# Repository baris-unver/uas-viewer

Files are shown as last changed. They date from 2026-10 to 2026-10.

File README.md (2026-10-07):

# SkyG Airframe Explorer

Interactive 3D models of SkyG Speed 90 (revision C6-9, `c6/`, also the site root), SkyG Speed 90B (carbon-tube fuselage, `c6b/`), SkyG Speed 120 (`c7/`) and SkyG Speed 180 (`c8/`); SkyG Speed 60 (`c5/`) is archived: exploded view, per-part print data, camera noses,
section cuts, CG and neutral-point marks. Single static page (three.js/WebGL); open `index.html` or the GitHub Pages site.

Generated from the design project by `scripts/viewer_C4.py`; published with `scripts/publish_site.sh`.

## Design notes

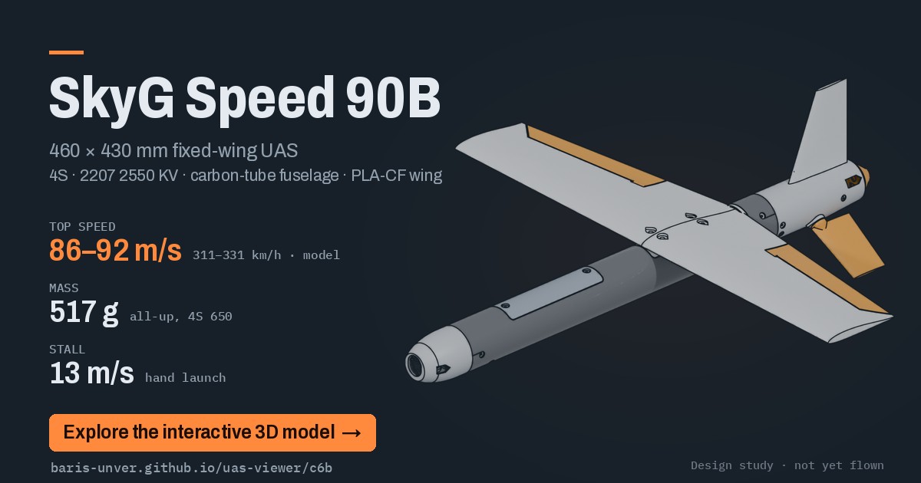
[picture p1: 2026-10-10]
share/C6B-card.jpg

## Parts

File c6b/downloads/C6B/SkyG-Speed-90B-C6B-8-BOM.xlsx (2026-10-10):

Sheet: Order list (BOM)
SkyG Speed 90B order list (BOM)
SkyG Speed 90B · revision C6B-8 · 2026-10-10
Line | Group | Item | Order qty | Qty per aircraft | Must-meet specification | Recommended product / search term | Installed where | Status | Source / note
1 | Avionics | Flight controller | 1 | 1 | 37 x 26 x 14 mm stack max, fixed-wing firmware (INAV/ArduPilot), PDB with current sensor >= 80 A, servo BEC 6 V | SpeedyBee F405 WING MINI | Equipment tray, wing-bay floor (foam tape + strap) | Sourced | https://ardupilot.org/plane/docs/common-speedybeef405wing.html - FC 5.6 g + PDB 5.5 g; 80 A sensor; servo BEC 5 V 4 A, 6 V by jumper (set 6 V); wireless USB extender for setup only; F405: no ArduPilot Lua scripting, so the rpm governor cannot run on it (open item)
2 | Avionics | GNSS + compass | 1 | 1 | M10 GNSS + compass, 25 x 25 x 7.7 mm, 5 V, UART + I2C | TBS M10Q GPS GLONASS (QMC5883 compass), 13.5 g | Bonded carrier under the PLA front hatch cover (its radio window), behind the battery, patch up | Sourced | https://www.robocombo.com/tbs-m10q-gps-glonass-4293 - battery rear stop x=136; compass near the battery leads: compassmot or disable it
3 | Radio | Receiver | 1 | 1 | ELRS 2.4 GHz, <=13x11x3 mm | RadioMaster RP1 V2 | On the equipment tray ahead of the flight controller (x 228-241) | Sourced | https://www.radiomasterrc.com/products/rp1-expresslrs-2-4ghz-nano-receiver; antenna: dipole in the fin on a u.FL coax (inside the carbon tube there is no radio)
4 | Radio | Transmitter | 1 | 0 | ELRS 2.4 GHz, model mixing for V-tail | e.g. RadioMaster Pocket ELRS or Boxer ELRS | Ground | Owner choice | Skip if you already have an ELRS radio
5 | Propulsion | Motor | 2 | 1 | 2207 class, about 2550 KV (4S racing), 5 mm prop shaft, 16 x 16 mm M3, bell <= 28 mm, body <= 21.5 mm, <= 34 g | 2207 2550KV 4S racing motor | Motor shroud (plate M1, 16 x 16 mm pattern) | Sourced | C6: about 600 W bursts; motor bulkhead at x=420.2 for the longer body
6 | Propulsion | Propeller (fixed) | 6 | 1 | APC 5 x 7.5E thin electric (LP05075E), 5 mm bore with adapter ring, pusher orientation, rated 30,000 rpm | APC 5x7.5E (LP05075E) | Motor bell, behind the spinner backplate; thin M5 nut | Class | C5-3: fixed prop with a 77 % flight-controller throttle cap. It hangs below the ground line at rest: expect broken props on belly landings, carry spares
7 | Propulsion | Prop adapter ring | 2 | 1 | APC adapter ring to the 5 mm motor shaft (LPARM12SF set, included with the prop) | APC LPARM12SF adapter rings | Prop hub bore | Class | C5-3; a folding yoke only for the optional folding prop
8 | Propulsion | ESC | 1 | 1 | 4-in-1 70 A AM32 (one channel used): 70 A / 100 A 3 s per channel, 3-8S, bidirectional DShot rpm telemetry, 33 x 43 mm, 13.4 g | HDZero Halo 4in1 70A ESC AM32 | Wing bay, flat on the flight controller (x 248-291), motor on M1 | Sourced | https://fpvdronemarket.com/hdzero-halo-4in1-70a-esc-am32 (2026-10-06: the single 65 A ESC was not available in Turkey). Replace the XT60 lead with XT30; only M1 signal, GND and telemetry from the SH1.0 lead; rpm telemetry feeds the governor. Order 1: if the M1 channel fails, move the motor to M2 (no spare ESC needed)
9 | Controls | Metal-gear micro servo | 4 | 3 | Emax ES9052MD (drawing): case 19.9 x 8.8 mm, 26.35 mm to the spline top, ears 29 mm with 2 mm holes at 25.1 mm, 15T 3.9 mm spline 4.2 mm from one end, metal gears, digital, 1.3 kg cm at 6 V, 5.5 g | Emax ES9052MD or ES9052MD HV (Promodelhobby, Turkey) | 1 wing bay (through the floor onto the bottom skin, output aft at x 323) + 2 tail module (through the F3 floor, output aft at x 374) | Sourced | KST X06 no longer available. No output bearing: check freeplay on the bench; 6 V servo rail
10 | Power | Flight battery | 3 | 1 | 4S LiPo 650 mAh, <= 60 x 31 x 21 mm, XT30, >= 100C (about 50 A bursts) | Tattu R-Line 4S 650 75C (60 x 31 x 21 mm, 74 g) | Front bay floor | Sourced | C6: high-C pack; full power lasts about 40-50 s
11 | Power | Balance charger | 1 | 0 | 4S LiPo balance charging, XT30 lead | e.g. ToolkitRC / ISDT small DC charger + XT30 lead | Ground | Owner choice
12 | Power | XT30 connector pairs | 4 | 1 | XT30 male/female | Amass XT30 | Battery-ESC/PDB | Class
13 | Video | FPV camera | 1 | 1 | 19 x 19 mm micro FPV camera with M2 side holes, <= 9 g (or 14 mm nano in a nano-to-micro bracket) | Micro 19 mm FPV camera, e.g. RunCam Phoenix 2 or Caddx Ratel 2 | N0M nose, on 2 x M2 pivot screws | Class | Digital micro cameras (Walksnail Avatar micro, HDZero micro) also fit; set the lens flush with the nose face
14 | Video | Video transmitter + antenna | 1 | 1 | Board <= 20 x 20 mm, height <= 6 mm, 25-200 mW, legal band/licence for your country and event | 20x20 analog or digital VTX with U.FL antenna | N0M nose shelf, flat | Class | Check competition video rules first; foam tape + zip tie on the shelf; antenna: vertical 5.8 GHz dipole (<= 26 x 3 mm) in the N0M nose clips; with N0MD a thin bare dipole <= 24 x 1.6 mm
15 | Structure | Carbon tube | 2 | 1 | 5.0 mm OD x 3.0 mm ID, >= 400 mm, straight | Pultruded carbon tube 5x3 mm x 500 mm (cut to 400) | Through both wing halves | Class | One tube through both halves (flat wing, no joiner since C4-7e)
17 | Controls | Music wire 2.0 mm | 1 | 2 | 2.0 mm spring steel, >= 250 mm | Music wire 2.0 mm | Aileron torque rods | Class | Two rods of ~95 mm: 12 mm horn bent down at the root with a 4 mm outboard pin at its tip; straight run on the hinge axis to y 80; the last 9 mm filed flat (0.3 mm deep, on the side opposite the horn) and epoxied into the D-bore in the aileron's root knuckle. Pushed in from the wing's root face; C6: one 90° bend per rod (horn leg 6 mm from the centreline), printed horn AHR/AHL glued on the leg
18 | Controls | Pushrods 1.2 mm with Z-bend | 4 | 4 | 1.2 mm steel pushrod with a factory Z-bend, >= 200 mm (cut to length: 2 aileron links about 20 mm, 2 tail pushrods about 75 mm) | Z Tip D1.2mm x 260mm Çelik Pushrod (LXMRC) | Z-bend in the servo arm (hole drilled 1.1 mm, reamed to 1.2 mm), 90° L-bend through the printed horn (reamed the same), keeper on the end | Sourced | https://www.promodelhobby.com/urun/z-tip-d1-2mm-x-260mm-celik-pushrod-itme-cubugu (C6 simple linkage, 2026-10-06)
19 | Controls | Pushrod keepers for 1.2 mm wire | 1 | 4 | Snap-on L-type pushrod keeper for 1.2 mm wire (pack of 5) | Pushrod Tutucu d1,2×L11mm (5 adet) | On the protruding L-bend end at each printed horn (2 ailerons, 2 stabilators) | Sourced | Promodelhobby, Bağlantı Elemanları (in stock 2026-10-06); unclip the tail pair to remove the tail module
20 | Controls | Z-bend pliers, 1.1 mm drill, 1.2 mm drill (as a hand reamer), small flat file | 1 | 0 | Pliers for the 90° L-bends; servo-arm and horn holes drilled 1.1 mm then reamed by hand with the 1.2 mm bit (zero play); flat file for the 0.3 mm flats | Du-Bro Z-bend pliers (or flat-nose pliers) | Tools: servo-arm and horn holes reamed to 1.2 mm, flats on the stabilator shafts (under the printed horns) and the torque rods | Class | No EZ connectors: Z-bends in the KST arms' 0.85 mm holes have less play
21 | Hardware | Steel countersunk screw M3 x 16 | 4 | 2 | Steel countersunk, hex socket (ISO 10642 / DIN 7991), A2 stainless or 8.8 | M3x16 steel countersunk screw | Wing mount, front screws (x = wing LE + 16), one in each wing half 6.5 mm from the centreline, in steel cup washers | Class | C6B (owner 2026-10-08): steel instead of nylon. Snug only: the nut bars are printed PETG-CF
22 | Hardware | M3 hex nut | 8 | 4 | 5.5 mm AF | M3 nuts | Wing screw nuts, two in each bonded nut bar | Class
23 | Hardware | M2 x 6 countersunk screws (joints) | 8 | 4 | M2 x 6 countersunk (DIN 965), steel | M2x6 countersunk screws | Tail-module joint (4: two each side, at the side and 25 deg below), each flush in a printed countersunk washer (CW) in a 5 mm hole in the F3 skin, into the tail coupler's bosses | Class
28 | Consumables | Kapton / thin clear tape | 1 |  | Kapton (polyimide) tape 6-10 mm wide, or thin clear tape | Kapton tape | Gap seals at the aileron hinge lines (applied with slack) | Class | The ailerons are pin-hinged, not tape-hinged
29 | Consumables | Adhesives | 1 |  | Medium CA + activator, 5-min or 30-min epoxy | CA + epoxy | Spars/joiner/tail | Class
30 | Consumables | Velcro strap + hook/loop | 2 | 1 | 10-12 mm battery strap | Battery strap 10x150 mm | Battery | Class
31 | Consumables | Heat shrink + silicone wire | 1 |  | 14 AWG red + black (battery lead and ESC feed, about 0.25 m each colour), 16 AWG black (motor phases, about 0.5 m), 28 AWG in four colours (signals); heat shrink 1.5 / 3 / 4.8 mm |  | Wiring | Class | Cut lengths per cable: Electrical Integration manual (C6, 2026-10-06)
32 | Structure | Silver steel rod 2.5 mm | 1 | 2 | 2.5 mm hardened silver steel, >= 100 mm (tail-panel pivot shafts) | 2.5 mm silver steel rod | Stabilator pivot shafts (2 x 50 mm) | Class | C6: about 6 x the bending stiffness of 1/16 in wire (flutter margin)
33 | Structure | Brass tube 3 mm | 1 | 2 | 3 mm OD x 0.225 mm wall (ID 2.55 mm), telescopes over the 2.5 mm shaft | K&S 3 mm x 0.225 brass tube | Stabilator bushings (2 x 10 mm) in the tail-module bosses | Class | Check the 1/16 in shaft turns freely without play
34 | Power | MR30 connector pairs | 3 | 1 | 3-pin MR30 (motor phases), male/female | Amass MR30 | Tail-module joint, ESC to motor | Class | Lets the tail module unplug
35 | Controls | Servo extension leads 100 mm | 4 | 2 | JR/Futaba 3-pin, 100 mm | Servo extension 100 mm | Tail servo leads: plug pairs lying flat on the floor beside the aileron servo (x 298-326, ahead of the tail joint) | Class | Unplug both, and the MR30, before pulling the tail module
36 | Video | JST-SH/GH lead with plug, 4-6 pin | 2 | 1 | Matches the VTX connector; 100 mm | VTX pigtail extension | Nose joint (VTX power + control) | Class | Choose after the VTX is selected
37 | Video | Camera pivot screws | 4 | 2 | M2 x 10 pan head + M2 washer 5 mm OD | M2x10 pan head screws + M2 washers | N0M nose side seats | Class | Carry spares; 2.5 mm thread engagement in the camera
38 | Test option (Pi) | Raspberry Pi camera | 1 | 0 | 25 x 23.862 mm CSI board, 4 x d2.2 holes on 21 x 12.5 mm | Raspberry Pi Camera Module 3 Wide (or v2 / Module 3) | N0P nose, on 4 posts | Sourced | https://www.raspberrypi.com/documentation/accessories/camera.html - only for the Pi test configuration
39 | Test option (Pi) | CSI camera ribbon | 1 | 0 | 15-pin 1 mm FPC (Pi 4 and earlier) or 22-pin 0.5 mm (Pi 5, Zero), >= 200 mm | Raspberry Pi camera cable | N0P nose to the Pi | Class | Choose to match the Raspberry Pi used
40 | Test option (Pi) | Pi board screws | 4 | 0 | M2 x 5 self-tapping (plastic) | M2x5 self-tapping screws | N0P posts | Class
41 | Test option (Pi) | Nose ballast | 1 | 0 | Up to about 6 g | Tungsten putty (or steel shot in epoxy) | Ceiling ballast cup in the Pi camera noses (N0P / N0PD, x 39-49), tape over | Class | Only if the balance needs it (SkyG Speed 90 with a Pi nose: about 4 g)
42 | Hardware | Motor screws M3 | 8 | 4 | M3 x 6 (check motor thread depth) | M3x6 socket screws | Motor to plate M1, fitted on the bench before the plate goes in | Class | Heads on the plate's front face sit in the bulkhead recesses
44 | Test equipment | Thrust stand / wattmeter | 1 | 0 | Measures thrust, current, rpm and power up to 70 A | Small motor thrust stand + inline wattmeter | Bench | Owner choice | Needed for the C5 test plan (thrust >= 500 g, current <= 30 A)
48 | Propulsion | Thin M5 nut | 4 | 1 | M5 DIN 439 thin nut (2.7 mm), steel; medium thread locker | M5 thin jam nut DIN 439 | Prop on the motor shaft | Class | The standard prop nut is too tall for the 460 mm limit
53 | Hardware | Steel countersunk screw M3 x 12 | 4 | 2 | Steel countersunk, hex socket (ISO 10642 / DIN 7991), A2 stainless or 8.8 | M3x12 steel countersunk screw | Wing mount, rear screws (x = wing LE + 58, ahead of the aileron horns), one in each wing half 6.5 mm from the centreline, in steel cup washers | Class | C6B (owner 2026-10-08): steel instead of nylon. Snug only: the nut bars are printed PETG-CF
83 | Hardware | Steel cup washer M3 (countersunk finishing washer) | 10 | 4 | Countersunk finishing (cup) washer for M3, about 8 mm OD x 1.8 mm, steel black oxide (or A2 stainless) | M3 countersunk finishing washer black | Under the four M3 wing screws, flush in the recesses in the wing top | Class | Owner 2026-10-08: steel cup washers on the wing and hatch screws (removed most often); the recess is 8.3 mm x 1.85 mm: check your washers
84 | Hardware | Steel cup washer M2 (countersunk finishing washer) | 10 | 2 | Countersunk finishing (cup) washer for M2, about 6 mm OD x 1.4 mm, A2 stainless (non-magnetic: the rear one is 5 mm from the GPS compass) | M2 countersunk finishing washer black | Under the two M2 hatch screws, flush in the recesses in the hatch cover | Class | Owner 2026-10-08; the recess is 6.3 mm x 1.45 mm: check your washers
54 | Hardware | M2 x 6 countersunk screws (motor plate) | 4 | 2 | M2 x 6 countersunk (DIN 965), steel | M2x6 countersunk screws | Motor plate M1: one each side, flush in a printed countersunk washer (CW) in a 5 mm counterbore in the tail module's side, into the plate's lugs (in pockets in the seat ring) | Class | C6B-6 (owner 2026-10-08): screwed in instead of bonded; the plate comes out for a different motor
55 | Consumables | Servo strap / zip tie + foam tape | 2 | 1 | 3 mm zip tie or 6 mm strap; double-sided foam tape | Small zip ties + servo tape | All three servos: foam tape on the bottom skin through the floor cut-outs, strap over the case | Class | Removable: the servos come out for motor service
56 | Structure | Steel rod 1.5 mm | 1 | 2 | 1.5 mm music wire or silver steel, >= 270 mm (2 x 132 mm) | Music wire 1.5 mm | Aileron hinge pin + spine on the hinge axis (y 82-214) | Class | Pushed in from the wingtip through the tip bore, the aileron and the two wing knuckles; bonded in the aileron with thin CA through its 3 glue holes, free in the knuckles and the tip. Plug the tip hole
57 | Video option (DJI) | DJI O4 Air Unit (Lite) | 1 | 1 | DJI O4 Air Unit (8.2 g with camera): camera 13.44 x 12.36 x 16.5 mm in a 14 x 20 mm mount, module 30 x 30 x 6 mm (4 x d2.6 on 25.5 mm), 3.7-13.2 V | DJI O4 Air Unit | N0O nose: camera in its mount clamped by 4 x M2 x 5 through the side bosses (fitted from the back); module in the separate duct insert DT (C6B-8) | Option | https://www.dji.com/o4-air-unit/specs (dimensions: O4 Air Unit Series User Manual v1.0, sec. 1.2) - replaces the micro camera + VTX; power from the SpeedyBee Vv pad set to the servo BEC (6 V jumper); needs airflow (shuts down after minutes on the bench) C6B-8: fit order antenna (clips, left wall), camera, then the module in the duct insert, then the insert through the spigot; cooling air from the NACA inlet on the right side, out through the tube
58 | Video option (DJI) | M2 x 5 pan head (O4 camera mount) | 4 | 4 | M2 x 5 pan head (or the screws supplied with the camera) | M2x5 pan head screws | N0O / N0OD side bosses into the camera mount | Class | At most 3.1 mm into the mount's d1.65 holes; fore-aft slots +-1 mm
59 | Video option (DJI) | Foam strip + tape (O4 module) | 1 | 1 | 2 x 1 mm foam strip, 25 mm; Kapton or aluminium tape | Double-sided foam tape, Kapton tape | Module retention in the nose duct | Class | Foam strip in the top groove, tape over the rear edge; nothing may cover the module's faces (they are the cooling surfaces)
60 | Video option (DJI) | O4 3-in-1 lead extension | 1 | 1 | ~200 mm, power + UART, plug at the nose joint | Silicone wire + JST-SH / matching plug | Nose to the flight controller in the wing bay | Class | MSP DisplayPort OSD on a spare SpeedyBee UART
61 | Consumables | Vent tape | 1 | 1 | Thin smooth tape (e.g. 3M 471 or Kapton), 15 mm | Vinyl or Kapton tape | Over the nose belly inlet, for record passes only (no openings in the tube or the hatch cover on C6B) | Class | Never over the DJI nose's duct openings (the module overheats in about a minute without them)
65 | Controls | 15T servo arms | 1 | 1 | 15T 3.9-4 mm spline arms: two-sided (aileron) with holes at 4.3 mm, one-sided (tail) with a hole at 6.7 mm; C6: holes drilled 1.1 mm and reamed to 1.2 mm for the 1.2 mm Z-bends (no play) | Arms supplied with the ES9052MD (drill a 0.85 mm hole at the radius if missing) or a KST X06 arm set | Aileron servo: two-sided arm; tail servos: one-sided arms | Class | Usually supplied with the servos
66 | Radio | u.FL extension 1.13 mm, about 250 mm | 1 | 1 | IPEX / u.FL male to u.FL female 1.13 mm coax, 200-300 mm | u.FL IPEX extension cable 1.13 mm | RP1 V2 receiver to the dipole in the fin (W07), u.FL joint at the tail joint | Class | C6: ELRS dipole in the fin (2026-10-06)
67 | Power | Dupont housings + crimps (1-pin, 4-pin) | 1 | 3 | 2.54 mm Dupont female housings with crimp terminals | Dupont connector kit 2.54 mm | ESC signal and GND on S1 (2 x 1-pin), receiver lead on the FC receiver header (4-pin) | Class
68 | Structure | Carbon-fibre tube 40 x 38 mm | 1 (2 m makes 6) | 320 mm | Roll-wrapped 3K carbon/epoxy, 40.0 mm OD x 38.0 mm ID (1 mm wall), about 178 g/m; straight, round within 0.1 mm | Karbon boru 40/38 mm 3K (Kompozit Pazari RFG 2 m; Karbonfiber Boru; PilotTR) | Fuselage x 50-350: camera nose plugs in the front, tail module onto the coupler at the back | Ordered (owner, 2026-10-07) | Measure the bore before printing (parameters: fuselage.tube.id); cut length 300 mm, windows and holes from the paper template; 42.8 g as cut
69 | Hardware | M2 x 6 countersunk screws (tube) | 12 | 8 | M2 x 6 countersunk (DIN 965 / ISO 7046), steel | M2x6 countersunk screws | Flush in a printed countersunk washer (CW; print 14: 8 in the tube, 4 at the tail joint, 2 at the motor plate) in each 5 mm hole in the tube: camera-nose joint (2, 10 mm from the tube's end), equipment tray (4), tail coupler (2, 40 deg above the side line, 12 mm from the tube's end; backup to the bond) | Class | Owner 2026-10-08: no screw heads standing out; the washer carries the head (no countersink in the 1 mm carbon)
70 | Consumables | Structural epoxy | 1 | ~3 g | 2-part structural epoxy (30-min working time or longer), bonds carbon and PLA; scuff the carbon with 120-grit and clean with alcohol first | e.g. UHU Plus Endfest 300, Loctite EA 3430 or laminating epoxy thickened with cotton flock | Nut bars, hatch lips, duct inserts, tail coupler and the wing saddle into / onto the tube | Class
71 | Consumables | Thin CA | 1 | ~1 g | Thin cyanoacrylate | Thin CA glue | Seal every cut edge and hole in the carbon tube | Class | Carbon conducts: a frayed edge can cut through a wire's insulation and short it
72 | Tools | Diamond cut-off discs + dust protection | 1 | - | Rotary-tool diamond cut-off discs (or reinforced abrasive), fine file, FFP3 mask, eye protection, vacuum at the disc or cut wet | Dremel 545 diamond disc or equivalent | Cutting the tube to length and its windows | Owner has a Dremel | Carbon dust is a lung irritant and conductive (keep it off electronics)
77 | Hardware | M2 x 6 countersunk screws (hatch) | 4 | 2 | M2 x 6 countersunk (DIN 965), steel | M2x6 countersunk screws | Front hatch cover, one at each end, into the bosses under the bonded lips | Class | C6B-4 (owner): no magnets
78 | Avionics | USB-C extension with socket | 1 | 1 | USB-C female socket board or panel-mount socket (about 10 x 8 mm) on a 150 mm USB-C extension, thin cable | USB-C female panel mount extension 15 cm | FC USB-C to the socket holder on the tray under the hatch cover (left of the GPS lead) | Class | C6B-4: FC access for setup, parameters and logs with the hatch cover off
89 | Consumables | Conformal coating | 1 | ~2 ml | Acrylic or silicone conformal coating for PCBs (e.g. MG Chemicals 419D / 422B), brush or spray | PCB conformal coating | Flight controller, ESC, receiver and VTX / O4 module boards (not on connectors, the USB socket, the barometer port or the module's heat faces) | Class | C6B-8 (owner: rain can reach the electronics): the cooling air reaches them through the tube; mask connectors before coating
90 | Consumables | Filament PLA-CF | 1 | 94 g | Bambu PLA-CF 1 kg (hardened-steel nozzle) | Bambu PLA-CF 1 kg (hardened-steel nozzle) | Wing halves WR/WL (2 walls, 8 % gyroid) | Bambu profile | C6B per-part filaments (design/MATERIALS-NOTES.md); one aircraft with the N0M nose
91 | Consumables | Filament PETG-CF | 1 | 55 g | Bambu PETG-CF 1 kg (hardened-steel nozzle) | Bambu PETG-CF 1 kg (hardened-steel nozzle) | Ailerons, equipment tray, tail coupler, nut bars, hatch lips, duct inserts, motor plate, spinner | Bambu profile | C6B per-part filaments (design/MATERIALS-NOTES.md); one aircraft with the N0M nose
92 | Consumables | Filament ASA | 1 | 21 g | Bambu ASA 1 kg (enclosed printer) | Bambu ASA 1 kg (enclosed printer) | Tail module F3 | Bambu profile | C6B per-part filaments (design/MATERIALS-NOTES.md); one aircraft with the N0M nose
93 | Consumables | Filament PETG | 1 | 20 g | Bambu PETG Basic 1 kg | Bambu PETG Basic 1 kg | Camera noses, VTX shelf, hatch cover, GPS carrier | Bambu profile | C6B per-part filaments (design/MATERIALS-NOTES.md); one aircraft with the N0M nose

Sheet: Printed parts
SkyG Speed 90B printed parts (Bambu Studio, Bambu Lab H2S 0.4 nozzle)
SkyG Speed 90B · revision C6B-8 · 2026-10-10
Part | Material | Mass (g) | Print time (h) | Walls | Infill
N0M-nose-micro-camera | PETG | 13.9 | 1.24 | 2 | 30 %
N0P-nose-pi-camera | PETG | 13.2 | 1.07 | 2 | 30 %
N0M-vtx-shelf | PETG | 0.8 | 0.13 | 2 | 30 %
N0O-nose-dji-o4 | PETG | 14.7 | 1.25 | 2 | 30 %
N0O-duct-insert | PLA Aero | 3.6 | 0.62 | 2 | 30 %
F3-tail-module | ASA | 14.3 | 2.02 | 2 | 30 %
HF-front-hatch | PETG | 4.3 | 1.42 | 2 | 30 %
HG-gps-carrier | PETG | 1.1 | 0.33 | 2 | 30 %
TR-equipment-tray | PETG-CF | 17.8 | 0.83 | 2 | 30 %
TC-tail-coupler | PETG-CF | 8.5 | 0.48 | 2 | 30 %
CW-countersunk-washer | PETG-CF | 0.1 | 0.1 | 2 | 30 %
WF-wing-window-filler | PETG-CF | 1.4 | 0.49 | 2 | 30 %
NB1-wing-nut-bar-front | PETG-CF | 1.2 | 0.2 | 2 | 30 %
NB2-wing-nut-bar-rear | PETG-CF | 1.3 | 0.2 | 2 | 30 %
HL1-hatch-lip-front | PETG-CF | 0.9 | 0.23 | 2 | 30 %
HL2-hatch-lip-rear | PETG-CF | 0.9 | 0.23 | 2 | 30 %
WR-wing-right | PLA-CF | 47.2 | 2.98 | 2 | 8 %
WL-wing-left | PLA-CF | 47.3 | 3 | 2 | 8 %
AR-aileron-right | PETG-CF | 4 | 1.22 | 1 | 5 %
AL-aileron-left | PETG-CF | 3.8 | 1.19 | 1 | 5 %
SR-stabilator-right | PETG-CF | 5.2 | 0.62 | 2 | 10 %
SL-stabilator-left | PETG-CF | 5.2 | 0.63 | 2 | 10 %
M1-motor-plate | PETG-CF | 2.1 | 0.23 | 4 | 40 %
FN-fin | ASA | 6.7 | 1.53 | 2 | 30 %
SP-spinner | PETG-CF | 1.6 | 0.23 | 4 | 40 %
AHR-aileron-horn-right | PETG-CF | 0.2 | 0.15 | 4 | 40 %
AHL-aileron-horn-left | PETG-CF | 0.2 | 0.15 | 4 | 40 %
THR-tail-horn-right | PETG-CF | 0.3 | 0.13 | 4 | 40 %
THL-tail-horn-left | PETG-CF | 0.3 | 0.13 | 4 | 40 %
One aircraft (one aircraft with the N0M nose; N0P is an alternative part): 190.6 g, 20.1 h of printing.
Print every part with supports OFF, in the orientation of the user manual (all parts pass the print audit, design/DFAM-RULES.md).
Only one camera nose is needed; the other noses (and their dome ring or VTX shelf) are options.

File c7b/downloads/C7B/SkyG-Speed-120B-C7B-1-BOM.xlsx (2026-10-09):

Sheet: Order list (BOM)
SkyG Speed 120B order list (BOM)
SkyG Speed 120B · revision C7B-1 · 2026-10-09
Line | Group | Item | Order qty | Qty per aircraft | Must-meet specification | Recommended product / search term | Installed where | Status | Source / note
1 | Avionics | Flight controller | 1 | 1 | 37 x 26 x 14 mm stack max, fixed-wing firmware (INAV/ArduPilot), PDB with current sensor >= 80 A, servo BEC 6 V | SpeedyBee F405 WING MINI | Equipment tray, front bay: on two printed ledges above the ESC, under the front hatch (foam tape + strap) | Sourced | https://ardupilot.org/plane/docs/common-speedybeef405wing.html - FC 5.6 g + PDB 5.5 g; 80 A sensor; servo BEC 5 V 4 A, 6 V by jumper (set 6 V); F405: no ArduPilot Lua scripting, so no rpm governor: the throttle is capped (THR_MAX about 70 %) so the prop stays at 38,000 rpm on a full 6S pack (owner 2026-10-09: same FC as SkyG Speed 90B)
2 | Avionics | GNSS + compass | 1 | 1 | M10 GNSS + compass, 25 x 25 x 7.7 mm, 5 V, UART + I2C | TBS M10Q GPS GLONASS (QMC5883 compass), 13.5 g | Cradle under the PETG front hatch cover (its radio window), above the front battery pair, patch up | Sourced | https://www.robocombo.com/tbs-m10q-gps-glonass-4293 - the compass is 10-30 mm from the battery leads and the charge port: compassmot or disable it
3 | Radio | Receiver | 1 | 1 | ELRS 2.4 GHz, <=13x11x3 mm | RadioMaster RP1 V2 | On edge on the right FC ledge (x 100-113), foam tape | Sourced | https://www.radiomasterrc.com/products/rp1-expresslrs-2-4ghz-nano-receiver; antenna: dipole in the fin on a u.FL coax (inside the carbon tube there is no radio)
4 | Radio | Transmitter | 1 | 0 | ELRS 2.4 GHz, model mixing for V-tail | e.g. RadioMaster Pocket ELRS or Boxer ELRS | Ground | Owner choice | Skip if you already have an ELRS radio
5 | Propulsion | Motor | 2 | 1 | 2207 class rated for 6S, 2100-2200 KV, 5 mm shaft or M5 prop thread, 16 x 16 mm M3, bell <= 28 mm, body <= 21.5 mm, >= 50 A peak | T-Motor F50 2207 2150KV | Motor shroud (plate M1, 16 x 16 mm pattern) | Owner has | Same motor as SkyG Speed 60 (C5). T-Motor rates it for 24 V (6S): 50 mOhm, 54.8 A / 1273 W peak. Robocombo lists it (https://www.robocombo.com/t-motor-latest-f50-5inch-racing-motor-2150kv--4160, 0 in stock on 2026-10-02); alternative VCI 2207 Pro 2110KV (Pyrodrone, in stock). The Velox V3 1950KV (Robocombo stock) gives about 110 m/s. SkyG Speed 120B: owner has it (2026-10-09)
6 | Propulsion | Propeller (fixed) | 8 | 1 | Gemfan Vortex 5 x 7.5 (glass-fibre polyamide), 6.35 mm bore with the 5 mm adapter ring; spin-tested to 45,600 rpm before use; operating ceiling 38,000 rpm (throttle cap) | Gemfan 5x7.5E Vortex | Motor bell, behind the spinner backplate; thin M5 nut | Owner has | Owner has it (2026-10-09). No published rpm rating: spin-test each batch to 1.2 x the 38,000 rpm ceiling behind a shield, then inspect. No governor on the F405: THR_MAX about 70 % holds an unloaded prop on a full pack at 38,000 rpm. Pusher: mount the E front face toward the motor with the motor reversed in the ESC (5x7.5R: Pyrodrone import). Balance prop + spinner carefully
7 | Propulsion | Prop adapter ring | 2 | 1 | 5 mm ring from the Gemfan adapter set (3/4/5/6/7 mm, included) | Gemfan adapter rings (with the prop) | Prop hub bore | Class | C5-3; a folding yoke only for the optional folding prop
8 | Propulsion | ESC | 1 | 1 | 4-in-1 70 A AM32 (one channel used): 70 A / 100 A 3 s per channel, 3-8S (6S used), bidirectional DShot rpm telemetry, 33 x 43 mm, 13.4 g | HDZero Halo 4in1 70A ESC AM32 | Front bay: flat on two rails on the tray's front floor (x 86-129), under the FC; slid in from behind before the packs, motor on M1 | Sourced | https://fpvdronemarket.com/hdzero-halo-4in1-70a-esc-am32 (owner 2026-10-09: the same ESC as SkyG Speed 90B, the Sequre 70 A is not available). Replace the XT60 lead with XT30; only M1 signal, GND and telemetry from the SH1.0 lead. About 65 A at full throttle on the ground (model), 60 A at top speed: inside the 70 A channel rating. Order 1: if M1 fails, move the motor to M2
9 | Controls | Metal-gear micro servo | 4 | 3 | Emax ES9052MD (drawing): case 19.9 x 8.8 mm, 26.35 mm to the spline top, ears 29 mm with 2 mm holes at 25.1 mm, 15T 3.9 mm spline 4.2 mm from one end, metal gears, digital, 1.3 kg cm at 6 V, 5.5 g | Emax ES9052MD or ES9052MD HV (Promodelhobby, Turkey) | 1 wing bay (through the floor onto the bottom skin, output aft at x 323) + 2 tail module (through the F3 floor, output aft at x 374) | Sourced | KST X06 no longer available. No output bearing: check freeplay on the bench; 6 V servo rail
10 | Power | Flight battery | 8 | 4 | 3S LiPo 680 mAh, <= 81 x 15.5 x 20 mm, XT30, >= 95C; four per aircraft: each side-by-side pair in series (6S 680), the two pairs in parallel (6S 1360 mAh, 194 g) | BetaFPV LAVA II 3S 680 95C LiHV (2-pack) | On the tray under the wing (x 138-308 at the nominal balance position), strapped; stays in the aircraft | Sourced | https://fpvdronemarket.com/lava-ii-3s-battery-680mah-2pcs (2,323 TL per 2 on 2026-10-02); 48.5 g each. The packs stay in the aircraft and are charged through the port under the hatch (owner 2026-10-09). Charge to 4.20 V/cell (LiPo mode), not LiHV: 6S full = 25.2 V, the ESC's limit. Use four packs of the same batch and cycles; never connect the pairs at different voltages. Order 8: one set flies, one spare set
11 | Power | Balance charger | 1 | 0 | 6S LiPo balance charging at <= 1C (1.4 A), LiPo mode 4.20 V/cell, XT30 lead and a 6S (7-pin JST-XH) balance lead; storage-charge function | e.g. ToolkitRC / ISDT small DC charger + XT30 lead | Ground | Owner choice | Charge in the aircraft, attended, on a non-flammable surface; inspect the packs (tray out) after any hard landing
12 | Power | XT30 connector pairs | 6 | 2 | XT30 male/female | Amass XT30 | ESC lead to the charge / arming port; spare for the charger lead | Class
13 | Video | FPV camera | 1 | 1 | 19 x 19 mm micro FPV camera with M2 side holes, <= 9 g (or 14 mm nano in a nano-to-micro bracket) | Micro 19 mm FPV camera, e.g. RunCam Phoenix 2 or Caddx Ratel 2 | N0M nose, on 2 x M2 pivot screws | Class | Digital micro cameras (Walksnail Avatar micro, HDZero micro) also fit; set the lens flush with the nose face
14 | Video | Video transmitter + antenna | 1 | 1 | Board <= 20 x 20 mm, height <= 6 mm, 25-200 mW, legal band/licence for your country and event | 20x20 analog or digital VTX with U.FL antenna | N0M nose shelf, flat | Class | Check competition video rules first; foam tape + zip tie on the shelf; antenna: vertical 5.8 GHz dipole (<= 26 x 3 mm) in the N0M nose clips; with N0MD a thin bare dipole <= 24 x 1.6 mm
15 | Structure | Carbon tube | 2 | 1 | 5.0 mm OD x 3.0 mm ID, >= 400 mm, straight | Pultruded carbon tube 5x3 mm x 500 mm (cut to 400) | Through both wing halves | Class | One tube through both halves (flat wing, no joiner since C4-7e)
17 | Controls | Music wire 2.0 mm | 1 | 2 | 2.0 mm spring steel, >= 250 mm | Music wire 2.0 mm | Aileron torque rods | Class | Two rods of ~95 mm: 12 mm horn bent down at the root with a 4 mm outboard pin at its tip; straight run on the hinge axis to y 80; the last 9 mm filed flat (0.3 mm deep, on the side opposite the horn) and epoxied into the D-bore in the aileron's root knuckle. Pushed in from the wing's root face; C6: one 90° bend per rod (horn leg 6 mm from the centreline), printed horn AHR/AHL glued on the leg
18 | Controls | Pushrods 1.2 mm with Z-bend | 4 | 4 | 1.2 mm steel pushrod with a factory Z-bend, >= 200 mm (cut to length: 2 aileron links about 20 mm, 2 tail pushrods about 75 mm) | Z Tip D1.2mm x 260mm Çelik Pushrod (LXMRC) | Z-bend in the servo arm (hole drilled 1.1 mm, reamed to 1.2 mm), 90° L-bend through the printed horn (reamed the same), keeper on the end | Sourced | https://www.promodelhobby.com/urun/z-tip-d1-2mm-x-260mm-celik-pushrod-itme-cubugu (C6 simple linkage, 2026-10-06)
19 | Controls | Pushrod keepers for 1.2 mm wire | 1 | 4 | Snap-on L-type pushrod keeper for 1.2 mm wire (pack of 5) | Pushrod Tutucu d1,2×L11mm (5 adet) | On the protruding L-bend end at each printed horn (2 ailerons, 2 stabilators) | Sourced | Promodelhobby, Bağlantı Elemanları (in stock 2026-10-06); unclip the tail pair to remove the tail module
20 | Controls | Z-bend pliers, 1.1 mm drill, 1.2 mm drill (as a hand reamer), small flat file | 1 | 0 | Pliers for the 90° L-bends; servo-arm and horn holes drilled 1.1 mm then reamed by hand with the 1.2 mm bit (zero play); flat file for the 0.3 mm flats | Du-Bro Z-bend pliers (or flat-nose pliers) | Tools: servo-arm and horn holes reamed to 1.2 mm, flats on the stabilator shafts (under the printed horns) and the torque rods | Class | No EZ connectors: Z-bends in the KST arms' 0.85 mm holes have less play
21 | Hardware | Steel countersunk screw M3 x 16 | 4 | 2 | Steel countersunk, hex socket (ISO 10642 / DIN 7991), A2 stainless or 8.8 | M3x16 steel countersunk screw | Wing mount, front screws (x = wing LE + 16), one in each wing half 6.5 mm from the centreline, in steel cup washers | Class | C6B (owner 2026-10-08): steel instead of nylon. Snug only: the nut bars are printed PETG-CF
22 | Hardware | M3 hex nut | 8 | 4 | 5.5 mm AF | M3 nuts | Wing screw nuts, two in each bonded nut bar | Class
23 | Hardware | M2 x 6 countersunk screws (joints) | 8 | 4 | M2 x 6 countersunk (DIN 965), steel | M2x6 countersunk screws | Tail-module joint (4: two each side, at the side and 25 deg below), each flush in a printed countersunk washer (CW) in a 5 mm hole in the F3 skin, into the tail coupler's bosses | Class
28 | Consumables | Kapton / thin clear tape | 1 |  | Kapton (polyimide) tape 6-10 mm wide, or thin clear tape | Kapton tape | Gap seals at the aileron hinge lines (applied with slack) | Class | The ailerons are pin-hinged, not tape-hinged
29 | Consumables | Adhesives | 1 |  | Medium CA + activator, 5-min or 30-min epoxy | CA + epoxy | Spars/joiner/tail | Class
30 | Consumables | Velcro strap + hook/loop | 2 | 2 | 10-12 mm battery strap, >= 200 mm | Battery strap 10x150 mm | One round each pack pair and the tray floor (slots at x 180 and 266) | Class
31 | Consumables | Heat shrink + silicone wire | 1 |  | 14 AWG red + black (battery lead and ESC feed, about 0.25 m each colour), 16 AWG black (motor phases, about 0.5 m), 28 AWG in four colours (signals); heat shrink 1.5 / 3 / 4.8 mm |  | Wiring | Class | Cut lengths per cable: Electrical Integration manual (C6, 2026-10-06)
32 | Structure | Silver steel rod 2.5 mm | 1 | 2 | 2.5 mm hardened silver steel, >= 120 mm (tail-panel pivot shafts) | 2.5 mm silver steel rod | Stabilator pivot shafts (2 x 59 mm) | Class | C6: about 6 x the bending stiffness of 1/16 in wire (flutter margin)
33 | Structure | Brass tube 3 mm | 1 | 2 | 3 mm OD x 0.225 mm wall (ID 2.55 mm), telescopes over the 2.5 mm shaft | K&S 3 mm x 0.225 brass tube | Stabilator bushings (2 x 10 mm) in the tail-module bosses | Class | Check the 1/16 in shaft turns freely without play
34 | Power | MR30 connector pairs | 3 | 1 | 3-pin MR30 (motor phases), male/female | Amass MR30 | Tail-module joint, ESC to motor | Class | Lets the tail module unplug
35 | Controls | Servo extension leads 300 mm | 4 | 3 | JR/Futaba 3-pin, 300 mm | Servo extension 300 mm | Tail servo leads (plug pairs beside the aileron servo) and the aileron servo lead, along the tube walls past the packs to the FC in the front bay | Class | C7B: the FC is in the front bay, about 200 mm ahead of the aileron servo
36 | Video | JST-SH/GH lead with plug, 4-6 pin | 2 | 1 | Matches the VTX connector; 100 mm | VTX pigtail extension | Nose joint (VTX power + control) | Class | Choose after the VTX is selected
37 | Video | Camera pivot screws | 4 | 2 | M2 x 10 pan head + M2 washer 5 mm OD | M2x10 pan head screws + M2 washers | N0M nose side seats | Class | Carry spares; 2.5 mm thread engagement in the camera
38 | Test option (Pi) | Raspberry Pi camera | 1 | 0 | 25 x 23.862 mm CSI board, 4 x d2.2 holes on 21 x 12.5 mm | Raspberry Pi Camera Module 3 Wide (or v2 / Module 3) | N0P nose, on 4 posts | Sourced | https://www.raspberrypi.com/documentation/accessories/camera.html - only for the Pi test configuration
39 | Test option (Pi) | CSI camera ribbon | 1 | 0 | 15-pin 1 mm FPC (Pi 4 and earlier) or 22-pin 0.5 mm (Pi 5, Zero), >= 200 mm | Raspberry Pi camera cable | N0P nose to the Pi | Class | Choose to match the Raspberry Pi used
40 | Test option (Pi) | Pi board screws | 4 | 0 | M2 x 5 self-tapping (plastic) | M2x5 self-tapping screws | N0P posts | Class
41 | Test option (Pi) | Nose ballast | 1 | 0 | Up to about 6 g | Tungsten putty (or steel shot in epoxy) | Ceiling ballast cup in the Pi camera noses (N0P / N0PD, x 39-49), tape over | Class | Only if the balance needs it (SkyG Speed 90 with a Pi nose: about 4 g)
42 | Hardware | Motor screws M3 | 8 | 4 | M3 x 6 (check motor thread depth) | M3x6 socket screws | Motor to plate M1, fitted on the bench before the plate goes in | Class | Heads on the plate's front face sit in the bulkhead recesses
44 | Test equipment | Thrust stand / wattmeter | 1 | 0 | Measures thrust, current, rpm and power up to 70 A | Small motor thrust stand + inline wattmeter | Bench | Owner choice | Needed for the C5 test plan (thrust >= 500 g, current <= 30 A)
48 | Propulsion | Thin M5 nut | 4 | 1 | M5 DIN 439 thin nut (2.7 mm), steel; medium thread locker | M5 thin jam nut DIN 439 | Prop on the motor shaft | Class | The standard prop nut is too tall for the 460 mm limit
53 | Hardware | Steel countersunk screw M3 x 12 | 4 | 2 | Steel countersunk, hex socket (ISO 10642 / DIN 7991), A2 stainless or 8.8 | M3x12 steel countersunk screw | Wing mount, rear screws (x = wing LE + 58, ahead of the aileron horns), one in each wing half 6.5 mm from the centreline, in steel cup washers | Class | C6B (owner 2026-10-08): steel instead of nylon. Snug only: the nut bars are printed PETG-CF
83 | Hardware | Steel cup washer M3 (countersunk finishing washer) | 10 | 4 | Countersunk finishing (cup) washer for M3, about 8 mm OD x 1.8 mm, steel black oxide (or A2 stainless) | M3 countersunk finishing washer black | Under the four M3 wing screws, flush in the recesses in the wing top | Class | Owner 2026-10-08: steel cup washers on the wing and hatch screws (removed most often); the recess is 8.3 mm x 1.85 mm: check your washers
84 | Hardware | Steel cup washer M2 (countersunk finishing washer) | 10 | 2 | Countersunk finishing (cup) washer for M2, about 6 mm OD x 1.4 mm, A2 stainless (non-magnetic: the rear one is 5 mm from the GPS compass) | M2 countersunk finishing washer black | Under the two M2 hatch screws, flush in the recesses in the hatch cover | Class | Owner 2026-10-08; the recess is 6.3 mm x 1.45 mm: check your washers
54 | Hardware | M2 x 6 countersunk screws (motor plate) | 4 | 2 | M2 x 6 countersunk (DIN 965), steel | M2x6 countersunk screws | Motor plate M1: one each side, flush in a printed countersunk washer (CW) in a 5 mm counterbore in the tail module's side, into the plate's lugs (in pockets in the seat ring) | Class | C6B-6 (owner 2026-10-08): screwed in instead of bonded; the plate comes out for a different motor
55 | Consumables | Servo strap / zip tie + foam tape | 2 | 1 | 3 mm zip tie or 6 mm strap; double-sided foam tape | Small zip ties + servo tape | All three servos: foam tape on the bottom skin through the floor cut-outs, strap over the case | Class | Removable: the servos come out for motor service
56 | Structure | Steel rod 1.5 mm | 1 | 2 | 1.5 mm music wire or silver steel, >= 270 mm (2 x 132 mm) | Music wire 1.5 mm | Aileron hinge pin + spine on the hinge axis (y 82-214) | Class | Pushed in from the wingtip through the tip bore, the aileron and the two wing knuckles; bonded in the aileron with thin CA through its 3 glue holes, free in the knuckles and the tip. Plug the tip hole
57 | Video option (DJI) | DJI O4 Air Unit (Lite) | 1 | 1 | DJI O4 Air Unit (8.2 g with camera): camera 13.44 x 12.36 x 16.5 mm in a 14 x 20 mm mount, module 30 x 30 x 6 mm (4 x d2.6 on 25.5 mm), 3.7-13.2 V | DJI O4 Air Unit | N0O or N0OD nose (camera + module) | Option | https://www.dji.com/o4-air-unit/specs (dimensions: O4 Air Unit Series User Manual v1.0, sec. 1.2) - replaces the micro camera + VTX; power from the SpeedyBee Vv pad set to the servo BEC (6 V jumper); needs airflow (shuts down after minutes on the bench)
58 | Video option (DJI) | M2 x 5 pan head (O4 camera mount) | 4 | 4 | M2 x 5 pan head (or the screws supplied with the camera) | M2x5 pan head screws | N0O / N0OD side bosses into the camera mount | Class | At most 3.1 mm into the mount's d1.65 holes; fore-aft slots +-1 mm
59 | Video option (DJI) | Foam strip + tape (O4 module) | 1 | 1 | 2 x 1 mm foam strip, 25 mm; Kapton or aluminium tape | Double-sided foam tape, Kapton tape | Module retention in the nose duct | Class | Foam strip in the top groove, tape over the rear edge; nothing may cover the module's faces (they are the cooling surfaces)
60 | Video option (DJI) | O4 3-in-1 lead extension | 1 | 1 | ~200 mm, power + UART, plug at the nose joint | Silicone wire + JST-SH / matching plug | Nose to the flight controller in the wing bay | Class | MSP DisplayPort OSD on a spare SpeedyBee UART
61 | Consumables | Vent tape | 1 | 1 | Thin smooth tape (e.g. 3M 471 or Kapton), 15 mm | Vinyl or Kapton tape | Over the nose belly inlet, for record passes only (no openings in the tube or the hatch cover on C6B) | Class | Never over the DJI nose's duct openings (the module overheats in about a minute without them)
65 | Controls | 15T servo arms | 1 | 1 | 15T 3.9-4 mm spline arms: two-sided (aileron) with holes at 4.3 mm, one-sided (tail) with a hole at 6.7 mm; C6: holes drilled 1.1 mm and reamed to 1.2 mm for the 1.2 mm Z-bends (no play) | Arms supplied with the ES9052MD (drill a 0.85 mm hole at the radius if missing) or a KST X06 arm set | Aileron servo: two-sided arm; tail servos: one-sided arms | Class | Usually supplied with the servos
66 | Radio | u.FL extension 1.13 mm, about 250 mm | 1 | 1 | IPEX / u.FL male to u.FL female 1.13 mm coax, 200-300 mm | u.FL IPEX extension cable 1.13 mm | RP1 V2 receiver to the dipole in the fin (W07), u.FL joint at the tail joint | Class | C6: ELRS dipole in the fin (2026-10-06)
67 | Power | Dupont housings + crimps (1-pin, 4-pin) | 1 | 3 | 2.54 mm Dupont female housings with crimp terminals | Dupont connector kit 2.54 mm | ESC signal and GND on S1 (2 x 1-pin), receiver lead on the FC receiver header (4-pin) | Class
68 | Structure | Carbon-fibre tube 50 x 48 mm | 1 (2 m makes 6) | 320 mm | Roll-wrapped 3K carbon/epoxy, 50.0 mm OD x 48.0 mm ID (1 mm wall), about 224 g/m; straight, round within 0.1 mm | Karbon boru 50/48 mm 3K (Kompozit Pazari; Karbonfiber Boru) | Fuselage x 50-370: camera nose plugs in the front, tail module onto the coupler at the back | Owner has (2 m, 2026-10-07) | Measure the bore before printing (parameters: fuselage.tube.id); cut length 320 mm, windows and holes from the paper template; 62.6 g as cut
69 | Hardware | M2 x 6 countersunk screws (tube) | 12 | 8 | M2 x 6 countersunk (DIN 965 / ISO 7046), steel | M2x6 countersunk screws | Flush in a printed countersunk washer (CW; print 14: 8 in the tube, 4 at the tail joint, 2 at the motor plate) in each 5 mm hole in the tube: camera-nose joint (2, 10 mm from the tube's end), equipment tray (4), tail coupler (2, 40 deg above the side line, 12 mm from the tube's end; backup to the bond) | Class | Owner 2026-10-08: no screw heads standing out; the washer carries the head (no countersink in the 1 mm carbon)
70 | Consumables | Structural epoxy | 1 | ~3 g | 2-part structural epoxy (30-min working time or longer), bonds carbon and PLA; scuff the carbon with 120-grit and clean with alcohol first | e.g. UHU Plus Endfest 300, Loctite EA 3430 or laminating epoxy thickened with cotton flock | Nut bars, hatch lips, duct inserts, tail coupler and the wing saddle into / onto the tube | Class
71 | Consumables | Thin CA | 1 | ~1 g | Thin cyanoacrylate | Thin CA glue | Seal every cut edge and hole in the carbon tube | Class | Carbon conducts: a frayed edge can cut through a wire's insulation and short it
72 | Tools | Diamond cut-off discs + dust protection | 1 | - | Rotary-tool diamond cut-off discs (or reinforced abrasive), fine file, FFP3 mask, eye protection, vacuum at the disc or cut wet | Dremel 545 diamond disc or equivalent | Cutting the tube to length and its windows | Owner has a Dremel | Carbon dust is a lung irritant and conductive (keep it off electronics)
77 | Hardware | M2 x 6 countersunk screws (hatch) | 4 | 2 | M2 x 6 countersunk (DIN 965), steel | M2x6 countersunk screws | Front hatch cover, one at each end, into the bosses under the bonded lips | Class | C6B-4 (owner): no magnets
78 | Avionics | USB-C extension with socket | 1 | 1 | USB-C female socket board or panel-mount socket (about 10 x 8 mm) on a 150 mm USB-C extension, thin cable | USB-C female panel mount extension 15 cm | FC USB-C to a loose socket parked between the charge plugs on the front battery pair, under the hatch cover | Class | C7B: setup, parameters and logs with the hatch cover off
89 | Power | XT30 series adapter (2 into 1) | 2 | 2 | XT30 series harness: two female inputs to one male output, 16 AWG | XT30 series adapter cable (2S/series) | Adapter block on the front pack pair (one per pair) | Class | Makes each pair of 3S packs one 6S pack; check polarity and series wiring with a meter before the first plug-in
90 | Power | XT30 parallel adapter (2 into 1) | 1 | 1 | XT30 parallel harness: two female inputs to one male output, 14 AWG | XT30 parallel adapter cable | Adapter block: the two 6S pairs to the main lead | Class | Only connect pairs within 0.05 V/cell of each other
91 | Power | Balance series adapter 2 x 3S to 6S | 2 | 2 | JST-XH: two 3S (4-pin) inputs to one 6S (7-pin) output | JST-XH 2x3S to 6S balance adapter | Adapter block (one per pair) | Class | Lets the charger balance each 6S pair as one pack
92 | Power | 6S parallel balance board | 1 | 1 | Parallel charging board with two 6S JST-XH inputs (or a 2 x 6S parallel balance lead) and one 6S output | 6S parallel balance lead / small parallel charging board | Adapter block: its output is the 7-pin balance plug at the charge port | Class | The charger sees one 6S 1360 mAh pack
93 | Power | Charge / arming port leads | 1 | 1 | 14 AWG pair (main lead to the port XT30, about 80 mm) and the 7-pin balance lead to the port, about 80 mm | Silicone wire 14 AWG + JST-XH 7-pin extension | Front pack pair, under the hatch: XT30 (battery side) and 7-pin plug parked side by side | Class | Plug the ESC lead in to fly, the charger (XT30 + balance) to charge; with nothing plugged in the aircraft is dead
94 | Consumables | Filament PLA-CF | 1 | 94 g | Bambu PLA-CF 1 kg (hardened-steel nozzle) | Bambu PLA-CF 1 kg (hardened-steel nozzle) | Wing halves WR/WL (2 walls, 8 % gyroid) | Bambu profile | Per-part filaments as SkyG Speed 90B (design/MATERIALS-NOTES.md); one aircraft with the N0M nose
95 | Consumables | Filament PETG-CF | 1 | 63 g | Bambu PETG-CF 1 kg (hardened-steel nozzle) | Bambu PETG-CF 1 kg (hardened-steel nozzle) | Ailerons, equipment tray, tail coupler, nut bars, hatch lips, duct inserts, motor plate, spinner | Bambu profile | Per-part filaments as SkyG Speed 90B (design/MATERIALS-NOTES.md); one aircraft with the N0M nose
96 | Consumables | Filament PETG | 1 | 26 g | Bambu PETG Basic 1 kg | Bambu PETG Basic 1 kg | Camera noses, VTX shelf, hatch cover, GPS carrier | Bambu profile | Per-part filaments as SkyG Speed 90B (design/MATERIALS-NOTES.md); one aircraft with the N0M nose
97 | Consumables | Filament ASA | 1 | 22 g | Bambu ASA 1 kg (enclosed printer) | Bambu ASA 1 kg (enclosed printer) | Tail module F3 | Bambu profile | Per-part filaments as SkyG Speed 90B (design/MATERIALS-NOTES.md); one aircraft with the N0M nose
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

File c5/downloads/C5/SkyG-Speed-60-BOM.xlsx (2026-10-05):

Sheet: Order list (BOM)
SkyG Speed 60 order list (BOM)
SkyG Speed 60 · revision C5-9 · 2026-10-01
Line | Group | Item | Order qty | Qty per aircraft | Must-meet specification | Recommended product / search term | Installed where | Status | Source / note
1 | Avionics | Flight controller | 1 | 1 | 37 x 26 x 14 mm stack max, fixed-wing firmware (INAV/ArduPilot), PDB with current sensor >= 80 A, servo BEC 6 V | SpeedyBee F405 WING MINI | Wing bay floor (foam tape + strap) | Sourced | https://ardupilot.org/plane/docs/common-speedybeef405wing.html - FC 5.6 g + PDB 5.5 g; 80 A sensor; servo BEC 5 V 4 A, 6 V by jumper (set 6 V); wireless USB extender for setup only
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

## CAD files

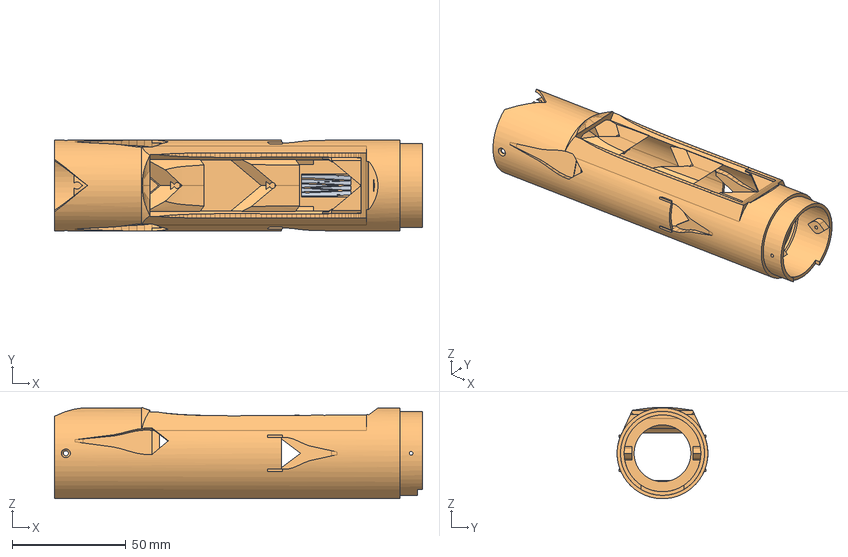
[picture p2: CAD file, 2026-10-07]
c6/downloads/C6/parts/F2-fuselage-main_C6-9.step
162.0 x 40.0 x 40.3 mm

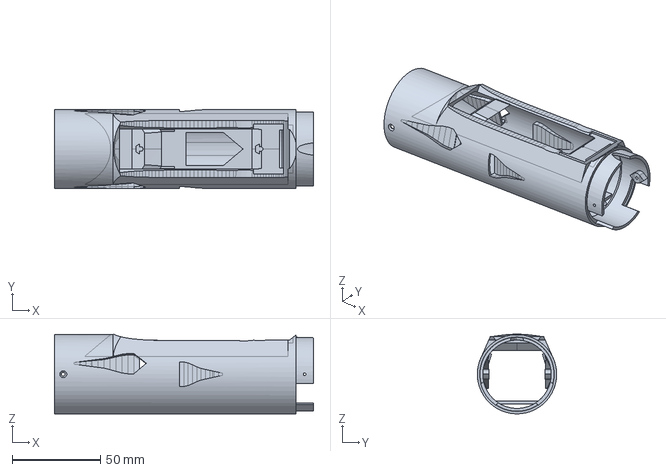
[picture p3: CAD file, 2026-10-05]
c8/downloads/C8/parts/F2-fuselage-main.step
147.0 x 45.0 x 45.3 mm

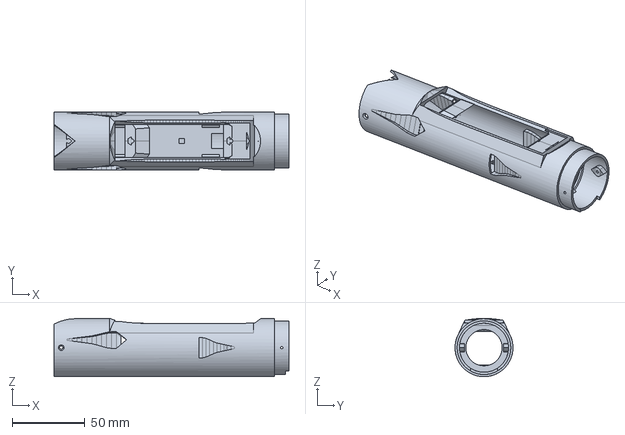
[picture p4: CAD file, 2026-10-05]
c5/downloads/C5/parts/F2-fuselage-main.step
162.0 x 40.0 x 40.3 mm

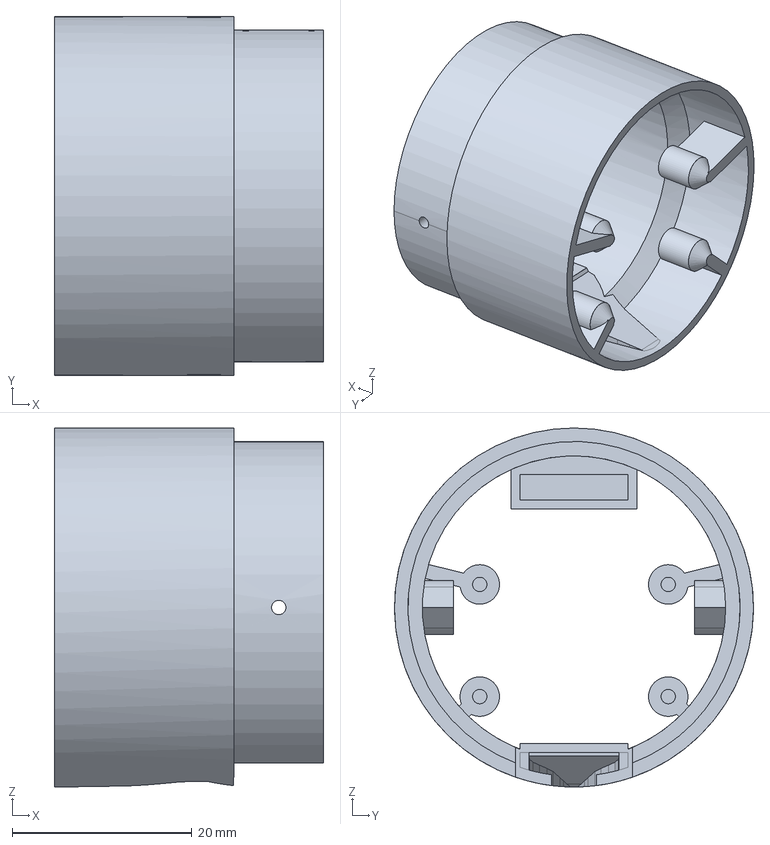
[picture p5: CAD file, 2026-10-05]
c5/downloads/C5/parts/N0PD-nose-pi-dome.step
30.0 x 40.0 x 40.0 mm

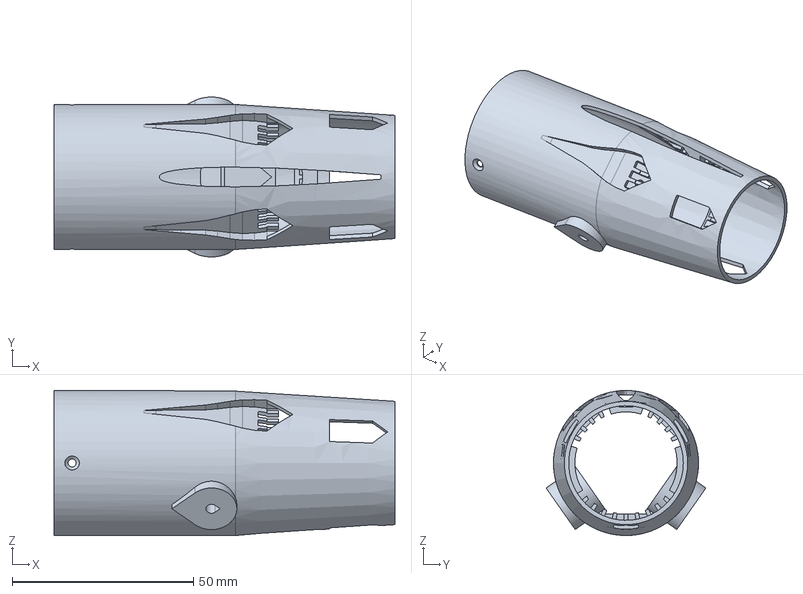
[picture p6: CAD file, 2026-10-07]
c6/downloads/C6/parts/F3-tail-module_C6-9.step
94.0 x 44.1 x 40.0 mm

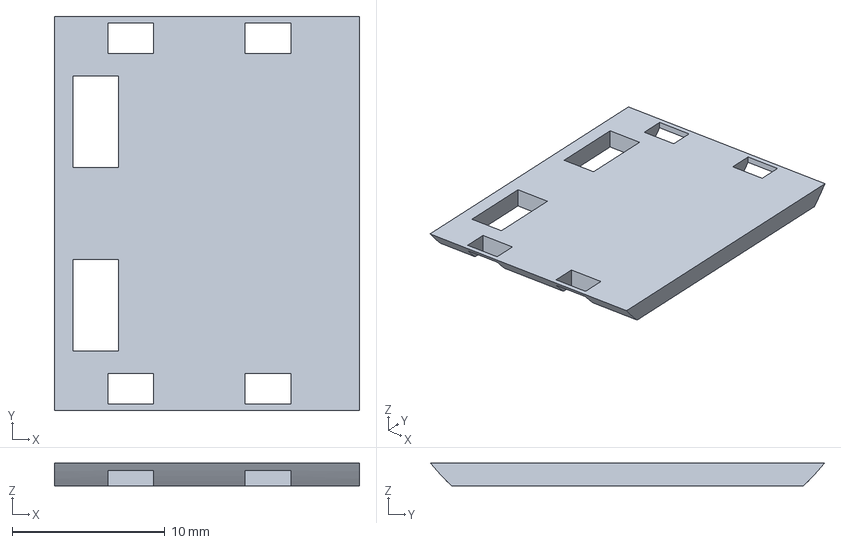
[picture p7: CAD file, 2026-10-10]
c6b/downloads/C6B/parts/N0M-vtx-shelf_C6B-8.step
20.0 x 25.8 x 1.50 mm

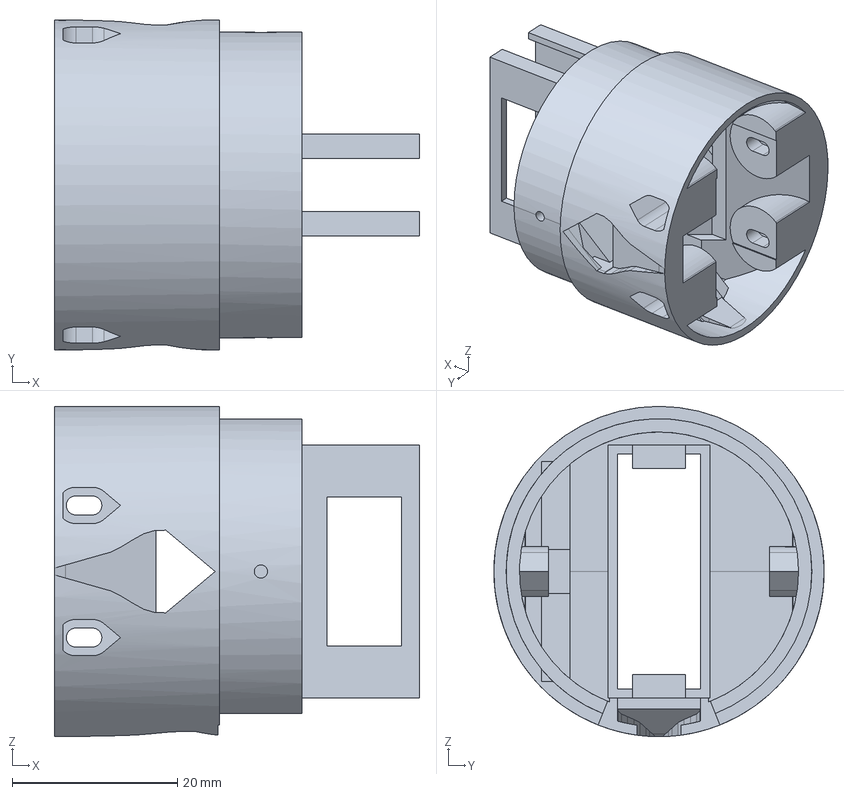
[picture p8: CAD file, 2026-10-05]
c7/downloads/C7/parts/N0OD-nose-dji-o4-dome.step
44.2 x 40.0 x 40.0 mm

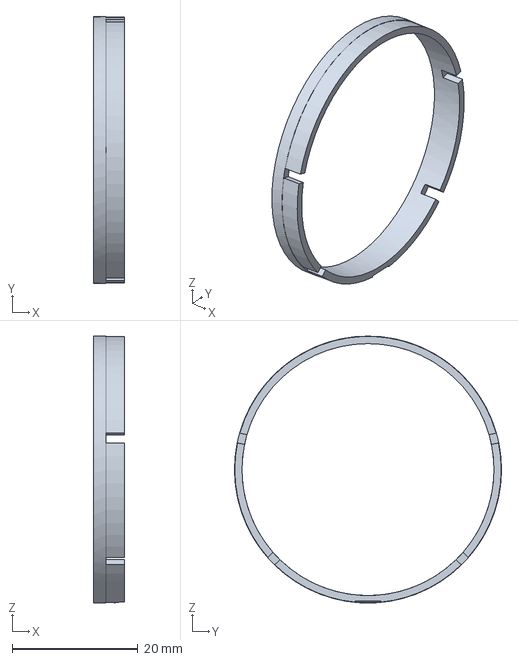
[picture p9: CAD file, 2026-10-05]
c8/downloads/C8/parts/N0PD-dome-ring.step
5.00 x 42.5 x 42.5 mm

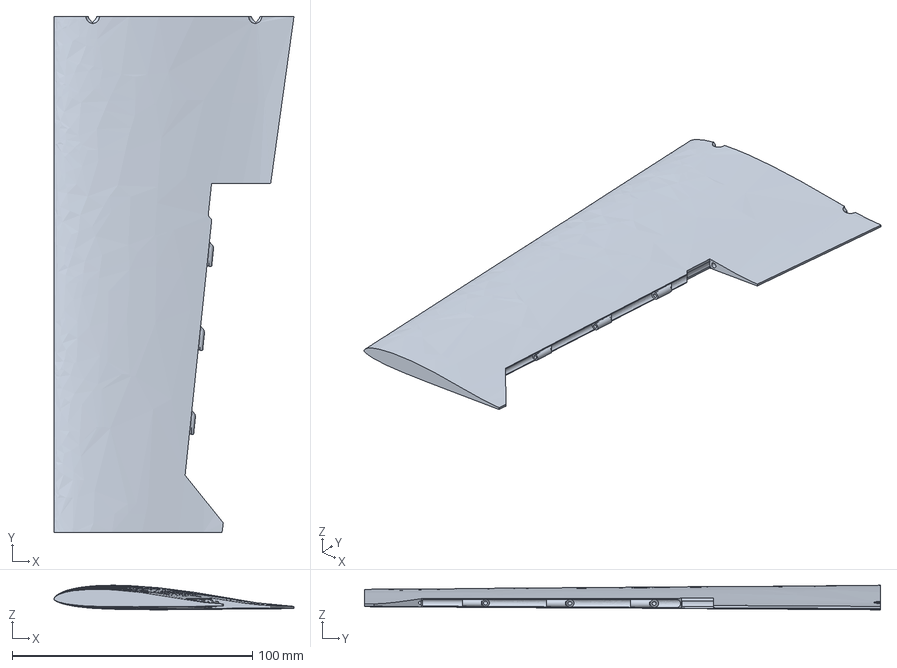
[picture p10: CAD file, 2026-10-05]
c5/downloads/C5/parts/WL-wing-left.step
100.0 x 215.0 x 10.3 mm

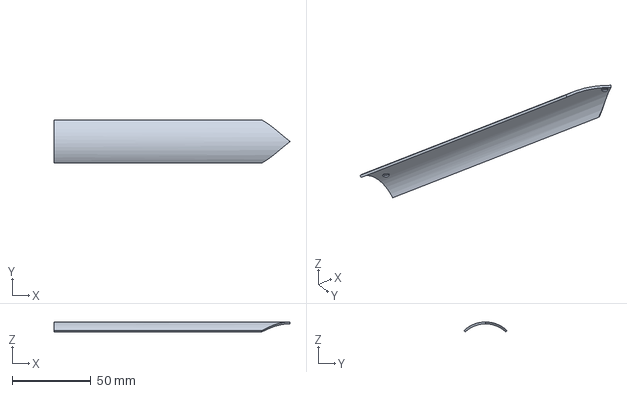
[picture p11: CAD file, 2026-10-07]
c6/downloads/C6/parts/HF-front-hatch_C6-9.step
149.7 x 27.6 x 6.38 mm

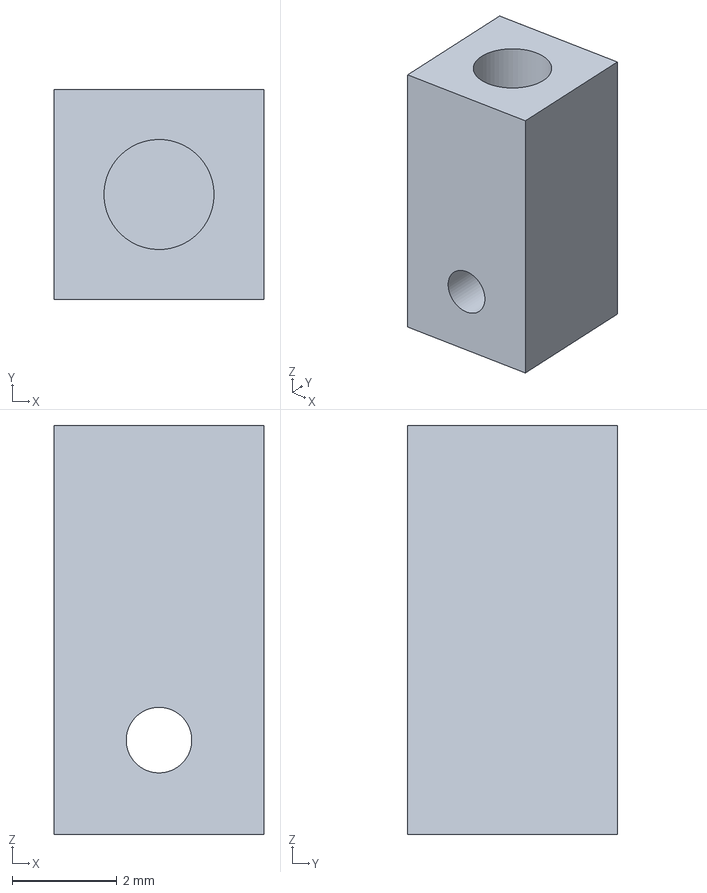
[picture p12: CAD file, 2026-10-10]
c6b/downloads/C6B/parts/AHL-aileron-horn-left_C6B-8.step
4.00 x 4.00 x 7.80 mm

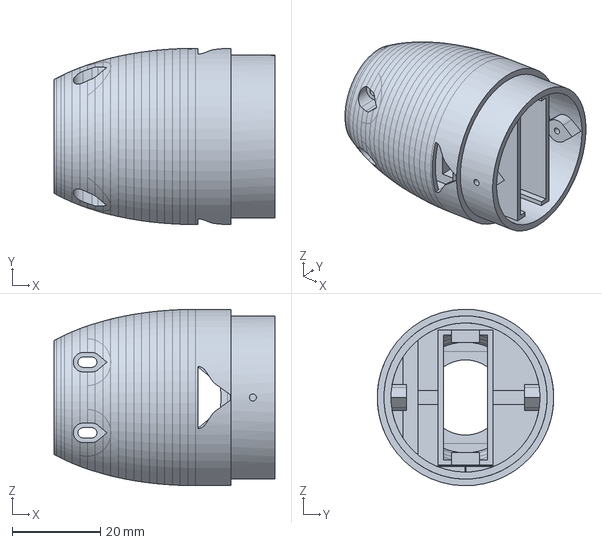
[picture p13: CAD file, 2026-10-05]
c7/downloads/C7/parts/N0O-nose-dji-o4.step
50.1 x 40.0 x 40.0 mm

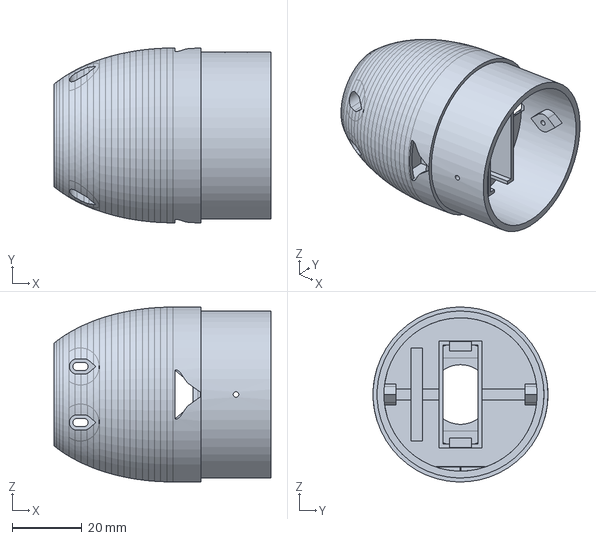
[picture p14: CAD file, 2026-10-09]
c7b/downloads/C7B/parts/N0O-nose-dji-o4_C7B-1.step
62.0 x 50.0 x 50.0 mm

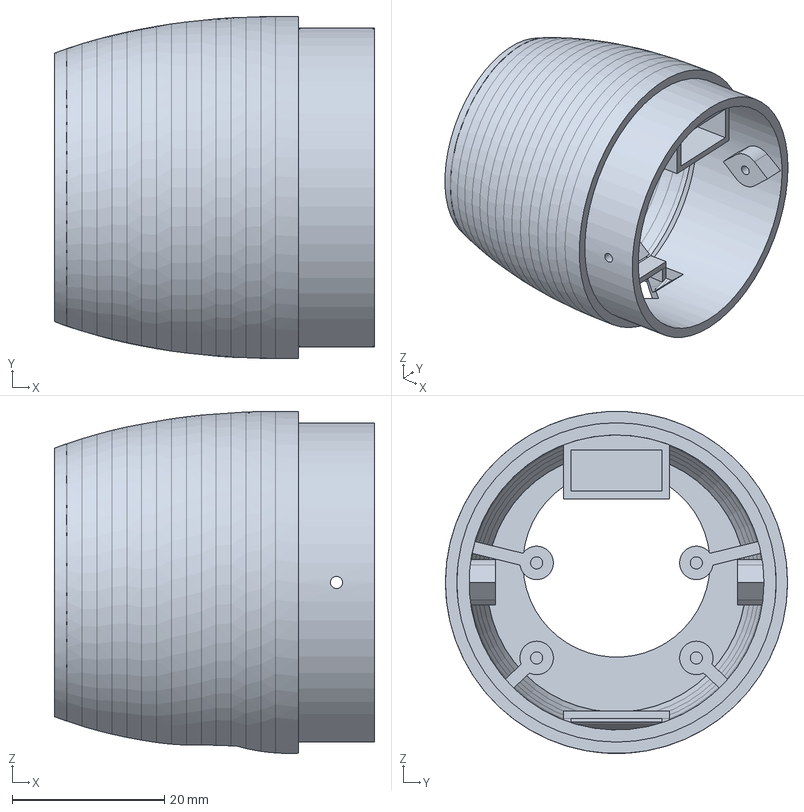
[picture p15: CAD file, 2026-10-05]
c8/downloads/C8/parts/N0P-nose-pi-camera.step
42.1 x 45.0 x 45.0 mm

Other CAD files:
c7/downloads/C7/parts/F2-fuselage-main.step
c5/downloads/C5/parts/SL-stabilator-left.step
c6/downloads/C6/parts/N0OD-dome-ring_C6-9.step
c6b/downloads/C6B/parts/N0O-duct-insert_C6B-8.step
c5/downloads/C5/parts/AL-aileron-left.step
c5/downloads/C5/parts/AR-aileron-right.step
c5/downloads/C5/parts/F1-fuselage-front.step
c5/downloads/C5/parts/F3-tail-module.step
c5/downloads/C5/parts/FN-fin.step
c5/downloads/C5/parts/HF-front-hatch.step
c5/downloads/C5/parts/HG-gps-carrier.step
c5/downloads/C5/parts/M1-motor-plate.step
c5/downloads/C5/parts/N0M-nose-micro-camera.step
c5/downloads/C5/parts/N0M-vtx-shelf.step
c5/downloads/C5/parts/N0MD-dome-ring.step
c5/downloads/C5/parts/N0MD-nose-micro-dome.step
c5/downloads/C5/parts/N0O-nose-dji-o4.step
c5/downloads/C5/parts/N0OD-dome-ring.step
c5/downloads/C5/parts/N0OD-nose-dji-o4-dome.step
c5/downloads/C5/parts/N0P-nose-pi-camera.step
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

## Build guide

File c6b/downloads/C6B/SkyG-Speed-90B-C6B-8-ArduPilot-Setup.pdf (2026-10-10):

# S KYG

# ARDUPILOTCONFIG

# SKYGSPEED90B

SpeedyBee F405 WING MINI (ArduPilot target: SpeedyBeeF405WING) · ArduPlane 4.5 or later

REVISION C6B-8 · 2026-10-10

# OVERVIEW

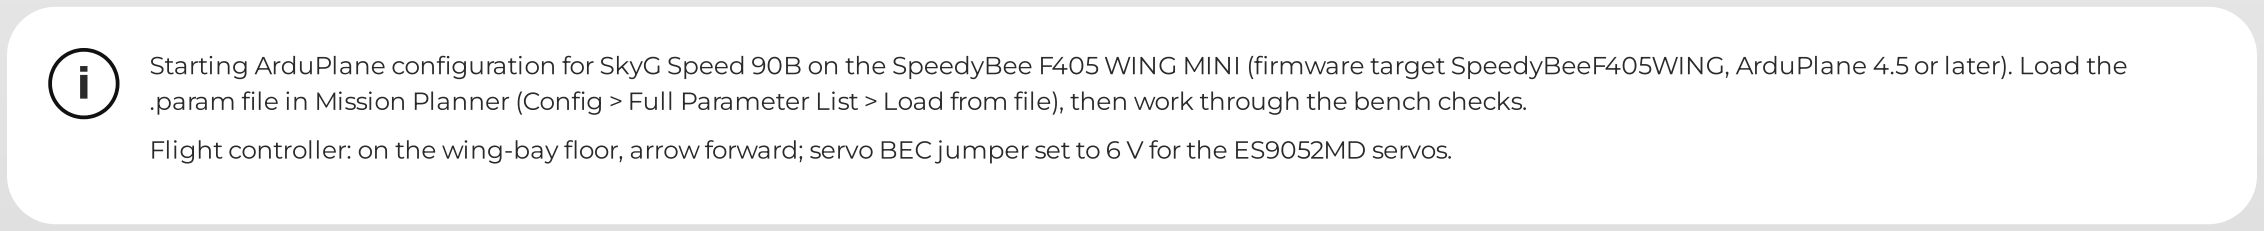
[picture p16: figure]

Starting ArduPlane configuration for SkyG Speed 90B on the SpeedyBee F405 WING MINI (firmware target SpeedyBeeF405WING, ArduPlane 4.5 or later). Load the

.param file in Mission Planner (Config > Full Parameter List > Load from file), then work through the bench checks.

Flight controller: on the wing-bay floor, arrow forward; servo BEC jumper set to 6 V for the ES9052MD servos.

WARNINGS

These are starting values, not a tested setup. Verify every output, direction and endpoint on the bench before the first flight.

Never raise THR_MAX: it protects the prop's rpm rating.

No airspeed sensor: the throttle limits do not stop a dive from building speed. Fly stage runs level.

SkyG Speed 90 was designed around an rpm governor at 29,500 rpm. ArduPilot cannot run the governor script on an F405 board. Until a governor is fitted (H7 flight controller

or a governed ESC), THR_MAX stays at 70 % and the stages that need more throttle are not flown (see the stage table).

SKYG SPEED 90B · REVISION C6B-8 · 2026-10-10 · 2

# FRAME,ORIENTATIONANDLOGGING

PARAMETER | VALUE | NOTE
AHRS_ORIENTATION | 0 | FC arrow forward, upright. Change only if the board is mounted otherwise.
LOG_BACKEND_TYPE | 1 | Logs to the microSD card.
LOG_DISARMED | 0 | No logging while disarmed.

Board mounted on the wing-bay floor, arrow forward, components up (build guide). Log to the microSD card.

# OUTPUTS

PARAMETER | VALUE | NOTE
SERVO1_FUNCTION | 70 | S1: throttle (motor ESC).
SERVO2_FUNCTION | 0 | S2: unused (shares the DShot timer group with S1).
SERVO3_FUNCTION | 4 | S3: aileron (one servo drives both ailerons).
SERVO4_FUNCTION | 79 | S4: V-tail left (left tail panel).
SERVO5_FUNCTION | 80 | S5: V-tail right (right tail panel).
SERVO3_TRIM | 1500 | Aileron neutral. The 3 deg reflex is set mechanically on each link, not here (one servo moves the ailerons in opposite directions).
SERVO3_MIN | 1178 | About 10 deg aileron (servo 29 deg at 2.79:1). Verify: about 3.5 mm at the aileron trailing edge.
SERVO3_MAX | 1822 | As SERVO3_MIN. Linkage limit +-20 deg aileron = +-807 us: never set beyond it.
SERVO4_TRIM | 1500 | Left panel neutral; trim mechanically first (collar on the shaft flat).

S1 drives the motor with bidirectional DShot (rpm telemetry for the prop-rpm check). S1 and S2 form one timer group: S2 stays unused. S3 drives the single aileron servo (both

ailerons through the torque rods). S4 and S5 drive the left and right tail panels as a V-tail mix.

Servo endpoints are calculated for the Emax ES9052MD (about 11.1 us per degree) and the linkages: aileron 2.79:1 (12 mm horn, 4.3 mm arm hole), tail 1.19:1 (8 mm horn, 6.7 mm

arm hole). They are starting points: set the final values by measuring the deflections on the bench.

# OUTPUTS

PARAMETER | VALUE | NOTE
SERVO4_MIN | 1232 | +-20 deg panel travel at 1.19:1 (servo 24 deg). Verify by measurement.
SERVO4_MAX | 1768 | As SERVO4_MIN.
SERVO5_TRIM | 1500 | Right panel neutral.
SERVO5_MIN | 1232 | As SERVO4_MIN.
SERVO5_MAX | 1768 | As SERVO4_MIN.
MIXING_GAIN | 0.5 | V-tail mix: full pitch alone gives half the panel travel (about +-10 deg), pitch plus yaw can reach the +-20 deg endpoints.
SERVO_RATE | 50 | Servo update rate (Hz) for the PWM groups; the ES9052MD is a digital servo and also accepts higher rates.

# MOTOR,ESCANDRPMTELEMETRY

PARAMETER | VALUE | NOTE
SERVO_BLH_MASK | 1 | DShot on output 1.
SERVO_BLH_OTYPE | 5 | DShot300. Verify the ESC accepts it.
SERVO_BLH_BDMASK | 1 | Bidirectional DShot (rpm telemetry) on output 1.
SERVO_BLH_POLES | 14 | Motor magnet poles (12N14P 2207 motors). Verify for your motor.
SERVO_DSHOT_ESC | 1 | BLHeli_32 / AM32 type ESC. Verify against your firmware version's list.
RPM1_TYPE | 5 | RPM sensor from ESC telemetry (logged).
RPM1_ESC_MASK | 1 | Motor on output 1.

Bidirectional DShot gives motor rpm in the logs: check on the thrust stand that the unloaded prop stays below 30,000 rpm on a full pack.

SERVO_DSHOT_ESC and the protocol depend on the ESC firmware (AM32 or BLHeli_32): verify on the bench.

# THROTTLE

PARAMETER | VALUE | NOTE
THR_MAX | 70 | no governor on the F405 yet: 30,000 / (2550 KV x 16.8 V) = 70 % keeps an unloaded prop on a full pack at its rating. Raise only when an rpm governor is fitted and proven on the thrust stand.
THR_MIN | 0 | Motor stops at zero throttle in flight (gliding, flutter abort).
THR_SLEWRATE | 100 | Throttle slew limit (% per second).
TRIM_THROTTLE | 35 | Cruise throttle guess for the synthetic-airspeed modes. Set from a log of level flight.

THR_MAX is the prop-rating cap: no governor on the F405 yet: 30,000 / (2550 KV x 16.8 V) = 70 % keeps an unloaded prop on a full pack at its rating. Raise only when an rpm

governor is fitted and proven on the thrust stand.

Speed stages are held by a transmitter throttle limit on a switch (LAUNCH / STAGE, table below), not by the flight controller. ArduPilot clips the throttle at THR_MAX in the

stabilised modes; check on the bench that MANUAL is clipped too, otherwise fly the stages in FBWA.

# NOAIRSPEEDSENSOR

PARAMETER | VALUE | NOTE
ARSPD_TYPE | 0 | No airspeed sensor.
ARSPD_USE | 0 | Do not use an airspeed sensor.
AIRSPEED_MIN | 17 | m/s; 1.25 x the 13.0 m/s stall.
AIRSPEED_CRUISE | 20 | m/s; cruise target for CRUISE / FBWB / RTL.
AIRSPEED_MAX | 30 | m/s; stage 1. Raise with each stage the test plan clears.

No airspeed sensor is fitted. ArduPilot uses a synthetic airspeed from GPS, wind estimate and throttle; FBWA and MANUAL do not need it.

Stall is about 13.0 m/s; AIRSPEED_MIN keeps 25 % margin. AIRSPEED_MAX matches the first speed stage and is raised with the stages.

# ATTITUDELIMITS,PITCHRATEANDYAWDAMPER

PARAMETER | VALUE | NOTE
PTCH_RATE_MAX | 94 | deg/s, stage 1 (30 m/s). See the stage table.
ROLL_LIMIT_DEG | 55 | Bank limit in the stabilised modes.
PTCH_LIM_MAX_DEG | 25 | Nose-up limit.
PTCH_LIM_MIN_DEG | -25 | Nose-down limit (no steep powered dives: speed builds fast).
YAW2SRV_DAMP | 0.15 | Yaw damper gain, starting point. Increase in small steps if the tail wags.
KFF_RDDRMIX | 0.5 | Rudder (V-tail yaw) mixed with aileron for coordinated turns.

Pitch rate is limited per speed stage so a full pull stays under the 6 g limit (table below); the file holds stage 1 (94 deg/s). Lower it before each faster stage.

The flight-dynamics model finds the Dutch roll about neutral at 13 m/s, so the yaw damper is required. Start low and tune in flight.

# RECEIVER,MODESANDARMING

PARAMETER | VALUE | NOTE
SERIAL1_PROTOCOL | 23 | RCIN (CRSF/ELRS) on UART1.
RC_OPTIONS | 8192 | Bit 13: 420k baud for ELRS.
RC5_OPTION | 153 | Channel 5 arms and disarms.
ARMING_RUDDER | 0 | No stick arming (switch only).
ARMING_CHECK | 1 | All pre-arm checks.
FLTMODE_CH | 6 | Flight-mode channel.
FLTMODE1 | 5 | FBWA (launch, stage runs).
FLTMODE2 | 5 | FBWA.
FLTMODE3 | 0 | MANUAL.

RadioMaster RP1 V2 ELRS receiver on UART1 (TX1/RX1) with CRSF. Arm with a switch on channel 5; flight modes on channel 6.

Hand launch in FBWA with the LAUNCH throttle position; no auto-takeoff is needed.

# RECEIVER,MODESANDARMING

PARAMETER | VALUE | NOTE
FLTMODE4 | 0 | MANUAL.
FLTMODE5 | 11 | RTL.
FLTMODE6 | 11 | RTL.

# GPSANDCOMPASS

PARAMETER | VALUE | NOTE
SERIAL3_PROTOCOL | 5 | GPS on UART3.
GPS_TYPE | 1 | Auto (u-blox M10). Named GPS1_TYPE in ArduPlane 4.6+.
COMPASS_ENABLE | 1 | Use the M10Q's compass (set 0 to fly without).
COMPASS_AUTODEC | 1 | Automatic declination.
COMPASS_AUTO_ROT | 2 | Detect the compass orientation during calibration. Verify the result against the GPS's arrow.

TBS M10Q on UART3 (TX3/RX3, the GPS pads) with its QMC5883 compass on I2C (SDA/SCL). The GPS sits behind the battery: its compass is 3-6 cm from the battery leads.

Either calibrate and run compass-motor interference compensation (compassmot) on the thrust stand, or disable the compass and fly on GPS heading (COMPASS_USE 0).

# BATTERYMONITORANDFAILSAFES

PARAMETER | VALUE | NOTE
BATT_MONITOR | 4 | Analog voltage and current.
BATT_VOLT_PIN | 10 | PDB voltage.
BATT_CURR_PIN | 11 | PDB current.
BATT_VOLT_MULT | 11.05 | Calibrate against a meter.
BATT_AMP_PERVLT | 50 | Calibrate against a meter or a known charge.
BATT_CAPACITY | 650 | mAh (4S 650).
BATT_LOW_VOLT | 13.6 | 3.4 V per cell under load.
BATT_LOW_MAH | 160 | About 25 % left.
BATT_FS_LOW_ACT | 1 | RTL on low battery.

WING MINI PDB sensors: voltage divider 1K:10K, current 50 A/V. Calibrate both against a meter.

Radio failsafe: RTL after 5 s without signal. Low battery: RTL.

# BATTERYMONITORANDFAILSAFES

PARAMETER | VALUE | NOTE
THR_FAILSAFE | 1 | Radio failsafe on.
FS_SHORT_ACTN | 0 | Short failsafe: circle (default).
FS_LONG_ACTN | 1 | Long failsafe: RTL.
FS_LONG_TIMEOUT | 5 | Seconds.

# OSDANDWIRELESSTELEMETRY

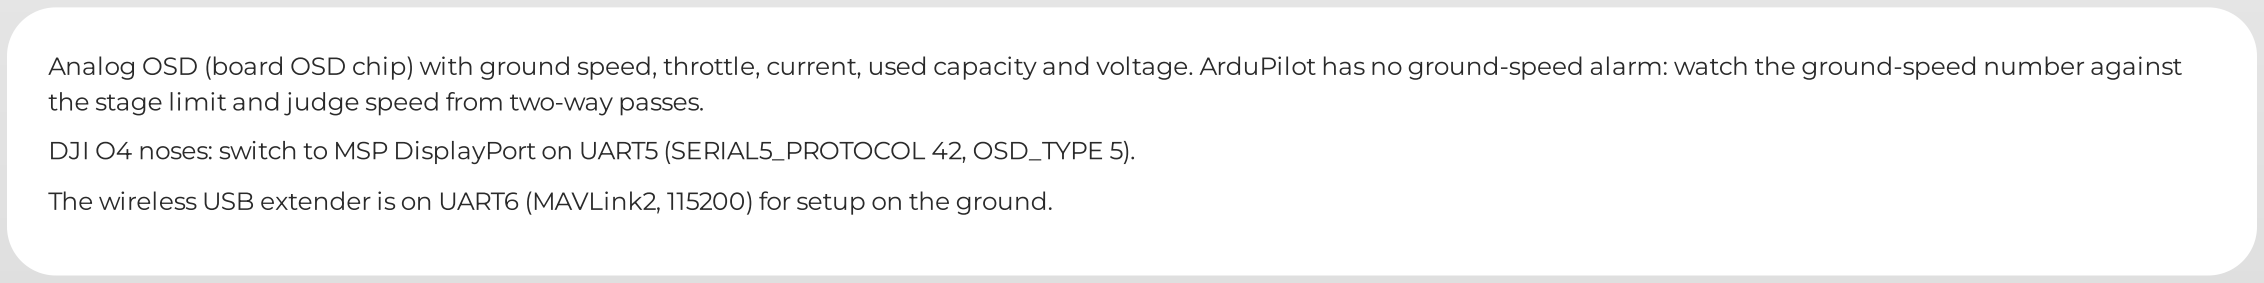
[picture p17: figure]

PARAMETER | VALUE | NOTE
OSD_TYPE | 1 | Analog OSD. Use 5 (MSP DisplayPort) with the DJI O4 noses.
OSD1_ENABLE | 1 | Screen 1.
OSD1_GSPEED_EN | 1 | GPS ground speed.
OSD1_THROTTLE_EN | 1 | Throttle %.
OSD1_CURRENT_EN | 1 | Current.
OSD1_BATUSED_EN | 1 | Used capacity (mAh).
OSD1_BAT_VOLT_EN | 1 | Battery voltage.
OSD_W_BATVOLT | 14.0 | Battery voltage warning (V).
SERIAL6_PROTOCOL | 2 | MAVLink2 on UART6 (wireless board).

Analog OSD (board OSD chip) with ground speed, throttle, current, used capacity and voltage. ArduPilot has no ground-speed alarm: watch the ground-speed number against

the stage limit and judge speed from two-way passes.

DJI O4 noses: switch to MSP DisplayPort on UART5 (SERIAL5_PROTOCOL 42, OSD_TYPE 5).

The wireless USB extender is on UART6 (MAVLink2, 115200) for setup on the ground.

# OSDANDWIRELESSTELEMETRY

PARAMETER | VALUE | NOTE
SERIAL6_BAUD | 115 | 115200 baud.

# BENCHCHECKSBEFOREFLIGHT

Props off. Power from a full pack; check the battery voltage and current readings against a meter.

Control directions in MANUAL: right stick -> right aileron trailing edge up, left down. Pull -> both tail-panel trailing edges up. Right rudder -> left panel trailing edge down,

right panel up (inverted V, panels below the fuselage). Fix with SERVOx_REVERSED.

Measure deflections with a protractor: aileron about +-10 deg, tail panels +-20 deg at the endpoints; adjust SERVOx_MIN/MAX. Nothing binds or buzzes at the ends.

FBWA: roll and pitch the airframe by hand; the surfaces must oppose the motion.

Thrust stand: THR_MAX 70 %; logged rpm with the prop unloaded on a full pack below 30,000; ESC current within its rating.

Transmitter: LAUNCH / STAGE switch set to the stage limit; confirm in the servo-output screen that full stick on STAGE gives the stage %.

Radio failsafe: switch the transmitter off with the motor at low throttle (props off): motor stops or RTL behaviour as set.

Compass: calibrate, then compassmot on the thrust stand (or COMPASS_USE 0).

GPS: 3D fix and the OSD shows ground speed.

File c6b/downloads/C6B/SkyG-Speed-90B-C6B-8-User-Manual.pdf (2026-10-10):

S

K

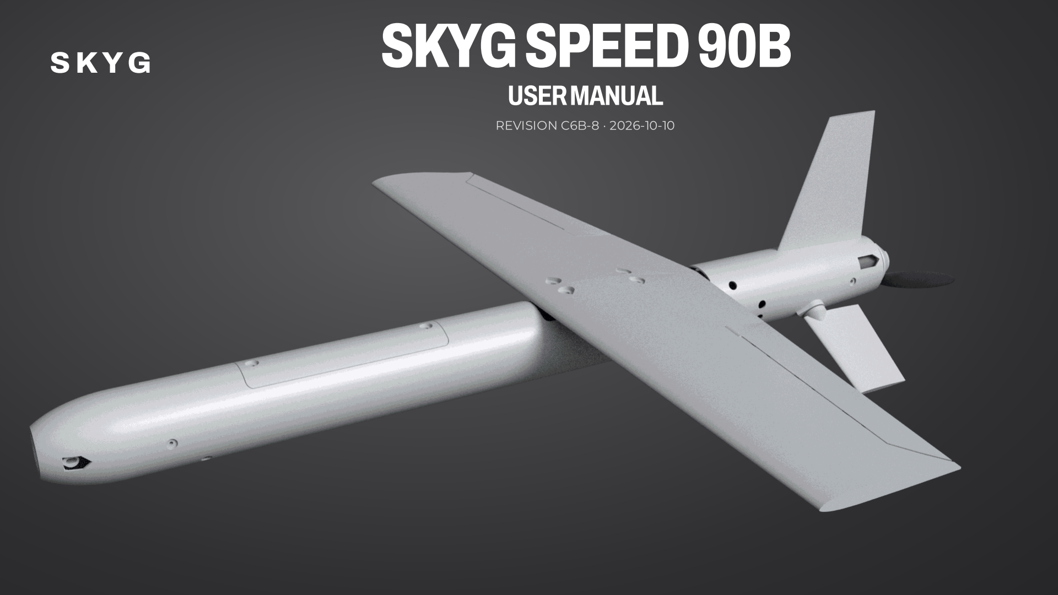
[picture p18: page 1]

Y

G

S

# KYG

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
VISIO
N

C

6
B

8 · 2

0

2

6

1

0

1

0

# PACKAGECONTENTS

SkyG Speed 90B user manual (this document).

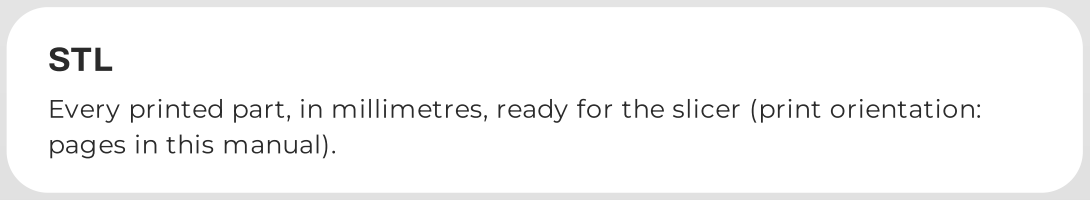
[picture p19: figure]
STL; pages in this manual).

Every printed part, in millimetres, ready for the slicer (print orientation:

Every printed part and the full assembly, for editing in any CAD program.

The wiring diagram as a separate large page.

Setup document and a starting .param file for the SpeedyBee F405 WING

Interactive 3D model (open the HTML file in a browser): every part exploded

Design record, parts list (BOM.csv), test plan and verification report.

SKY G | SKYG SPEED 90B | REVISION C6B-8 · 2026-10-10 | USER MANUAL | 2

# TABLEOFCONTENTS

### Introduction

General aircraft data | 05
Aerodynamic design | 06
Aerodynamic characteristics | 07
Performance and speed stages | 08
Compartment layout | 10
Camera nose variants | 11

### Recommended equipment

Recommended electronics | 13
Recommended accessories | 14
Powertrain | 15

### Print settings

Print settings | 17
Parts list | 19
Parts orientation | 20

### Assembly guide

Fuselage assembly | 31
Wing assembly | 32
Tail module | 35
Equipment and wiring | 41
Camera nose | 44
Final assembly | 46
Finishing build | 47
Wiring diagram | 48
Electrical integration | 49
ArduPilot configuration | 52
Flight test and speed stages | 53
SKY G | SKYG SPEED 90B | USER MANUAL | 3

# SKYGSPEED90B

SkyG Speed 90B is a compact, hand-launched speed aircraft: a 3D-

printed fuselage in three plug-together modules and a separate

camera nose, a 430 mm straight wing on a carbon spar, and an all-

moving canted tail driven by two micro servos. A single pusher motor

sits in the tail cone behind the tail.

The airframe is printed in foaming PLA Aero on a 0.4 mm nozzle; steel

and carbon parts carry the concentrated loads (spar, aileron hinge

pins and torque rods, tail shafts). Six interchangeable camera noses

take a micro FPV camera, a Raspberry Pi camera or a DJI O4 Air Unit,

each with an open or a clear-dome face.

It is built for straight-line speed: about 87 m/s finished with the

planned rpm governor, and about 63 m/s until that governor is fitted,

flown up through never-exceed stages.

SKY G | SKYG SPEED 90B | REVISION C6B-8 · 2026-10-10 | USER MANUAL | 4

# GENERALAIRCRAFTDATA

Wingspan | 430 mm
Wing area | 3.65 dm²
Length | 471 mm
Centre of gravity | 10 mm behind the wing leading edge at the root
All-up weight | 517 g (micro-camera nose)
Stall speed | 13.0 m/s
Top speed (model) | 86–87 m/s with the governor
Airfoil | MH45, ailerons 3° reflex
Root / tip chord | 100 / 70 mm
MAC | 86 mm
Aspect ratio | 5.1
Wing loading | 104 g/dm²
SKY G | SKYG SPEED 90B | REVISION C6B-8 · 2026-10-10 | USER MANUAL | 5

# AERODYNAMICDESIGN

The wing uses the MH45 section, a low-moment reflexed profile, with

both ailerons rigged 3° trailing edge up. The design CG is at 12 % of the

mean chord, 6.5 % static margin ahead of the neutral point (x 261 mm

from the nose datum): stable without a tail download penalty at speed.

Pitch and yaw come from two all-moving tail panels at 35° anhedral,

mixed like a V-tail, with a fixed fin on top. The Dutch roll is lightly

damped at low speed, so the flight controller's yaw damper is part of the

setup.

Flutter of the wing, ailerons and tail panels was analysed (strip theory

with the CAD-derived stiffness and masses): the lowest predicted

instability is 134 m/s, above 1.2 × the 90 m/s top stage. The test plan opens

the speed envelope in stages and measures the stiffness the margin

depends on.

SKY G | SKYG SPEED 90B | REVISION C6B-8 · 2026-10-10 | USER MANUAL | 6

# AERODYNAMICCHARACTERISTICS

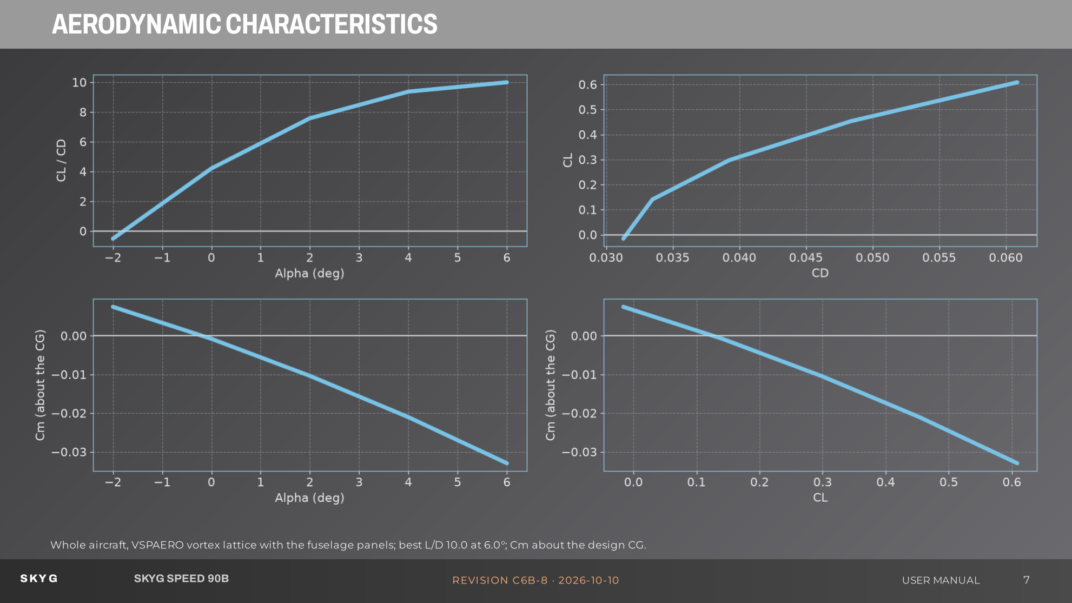
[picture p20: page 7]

Whole aircraft, VSPAERO vortex lattice with the fuselage panels; best L/D 10.0 at 6.0°; Cm about the design CG.

SKY G | SKYG SPEED 90B | REVISION C6B-8 · 2026-10-10 | USER MANUAL | 7

# PERFORMANCEANDSPEEDSTAGES

Motor | 2207 2550KV 4S racing motor
Propeller | APC 5x7.5E (LP05075E)
Battery | Tattu R-Line 4S 650 75C
Static thrust | 1064 g at 51 A (thrust / weight 2.06)
Throttle cap (prop rpm rating) | 70 %

Top speed

63–63 m/s now; 86–87 m/s with the

governor

Full-throttle time | about 0.7 min per pack (bursts of ≤ 10 s)
Stage Vne | STAGE throttle limit | Expected level speed
30 m/s | 28 % | 24 m/s
35 m/s | 32 % | 28 m/s
40 m/s | 36 % | 32 m/s
45 m/s | 41 % | 37 m/s
50 m/s | 45 % | 41 m/s
55 m/s | 50 % | 45 m/s
60 m/s | 55 % | 50 m/s
65 m/s | 59 % | 53 m/s
70 m/s | 64 % | 58 m/s
75 m/s | 69 % | 62 m/s
80 m/s | 70 % (needs the governor) | 63 m/s
85 m/s | 70 % (needs the governor) | 63 m/s
90 m/s | 70 % (needs the governor) | 63 m/s

No airspeed sensor: each stage is held by a throttle limit on a transmitter switch (LAUNCH =

full cap for the throw and climb-out only, STAGE = the limit). Level runs only; speed from

GPS two-way passes.

SKY G | SKYG SPEED 90B | REVISION C6B-8 · 2026-10-10 | USER MANUAL | 8

# FILES

i

Every printed part is supplied as STL (for printing) and

STEP (for editing), plus the complete assembly as one

STEP file. Left and right wing halves, ailerons and tail

panels are separate files because they are mirror

images. The interactive viewer in the package shows

every part, purchased item and cable in place.

SKY G | SKYG SPEED 90B | REVISION C6B-8 · 2026-10-10 | USER MANUAL | 9

# COMPARTMENTLAYOUT

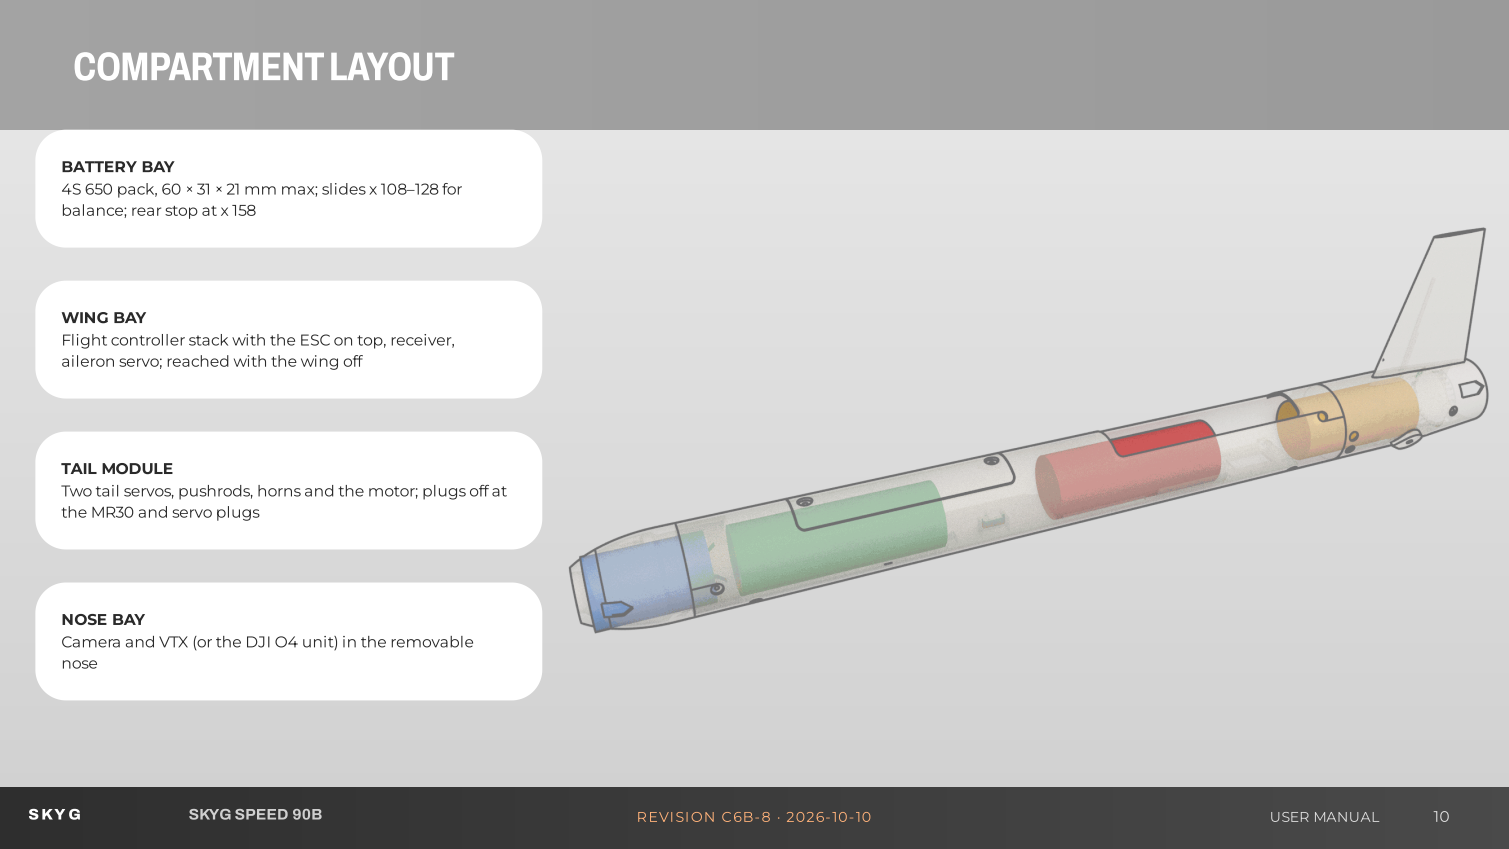
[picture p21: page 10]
BATTERY BAY; WING BAY; TAIL MODULE; NOSE BAY; nose; SKY G; SKYG SPEED 90B; REVISION C6B-8 · 2026-10-10; USER MANUAL

4S 650 pack, 60 × 31 × 21 mm max; slides x 108–128 for

balance; rear stop at x 158

Flight controller stack with the ESC on top, receiver,

aileron servo; reached with the wing off

Two tail servos, pushrods, horns and the motor; plugs off at

the MR30 and servo plugs

Camera and VTX (or the DJI O4 unit) in the removable

# CAMERANOSEVARIANTS

Nose | Camera | Battery centre for balance
N0M | 19 mm micro FPV camera + 20 × 20 VTX | x 114 mm
N0P | Raspberry Pi Camera Module 3 (test option) | x 89 mm (at its stop + nose ballast)
N0MD | micro camera behind a 40 mm dome, nano VTX under the hatch | x 0 mm
N0PD | Pi camera behind a dome | x 0 mm
N0O | DJI O4 Air Unit (Lite), ducted | x 0 mm
N0OD | DJI O4 behind a dome | x 0 mm
SKY G | SKYG SPEED 90B | REVISION C6B-8 · 2026-10-10 | USER MANUAL | 11

# RECOMMENDEDEQUIPMENT

i

This section lists the electronics and parts needed to complete the

aircraft. The full list with order quantities, specifications and sources is

BOM.csv in the package.

SKY G | SKYG SPEED 90B | REVISION C6B-8 · 2026-10-10 | USER MANUAL | 12

# RECOMMENDEDELECTRONICS

COMPONENT | MODEL / SPECIFICATION
Motor | 2207 2550KV 4S racing motor
Propeller (fixed) | APC 5x7.5E (LP05075E)
ESC | HDZero Halo 4in1 70A ESC AM32
Flight controller | SpeedyBee F405 WING MINI
GPS + compass | TBS M10Q GPS GLONASS (QMC5883 compass), 13.5 g
Servos | 3 × Emax ES9052MD or ES9052MD HV (Promodelhobby, Turkey)
Flight battery | Tattu R-Line 4S 650 75C (60 x 31 x 21 mm, 74 g)
Receiver | RadioMaster RP1 V2
FPV camera | Micro 19 mm FPV camera, e.g. RunCam Phoenix 2 or Caddx Ratel 2
Video transmitter + antenna | 20x20 analog or digital VTX with U.FL antenna
DJI O4 Air Unit (Lite) | DJI O4 Air Unit
SKY G | SKYG SPEED 90B | REVISION C6B-8 · 2026-10-10 | USER MANUAL | 13

# RECOMMENDEDACCESSORIES

ITEM | QTY
XT30 connector pairs | 1
Carbon tube | 1
Music wire 2.0 mm | 2
Pushrods 1.2 mm with Z-bend | 4
Pushrod keepers for 1.2 mm wire | 4
Z-bend pliers, 1.1 mm drill, 1.2 mm drill (as a hand reamer), small flat file | 0
Steel countersunk screw M3 x 16 | 2
M3 hex nut | 4
M2 x 6 countersunk screws (joints) | 4
Kapton / thin clear tape | as needed
Adhesives | as needed
Velcro strap + hook/loop | 1
Heat shrink + silicone wire | as needed
Silver steel rod 2.5 mm | 2
Brass tube 3 mm | 2
MR30 connector pairs | 1
Servo extension leads 100 mm | 2
ITEM | QTY
Motor screws M3 | 4
Steel countersunk screw M3 x 12 | 2
Steel cup washer M3 (countersunk finishing washer) | 4
Steel cup washer M2 (countersunk finishing washer) | 2
M2 x 6 countersunk screws (motor plate) | 2
Servo strap / zip tie + foam tape | 1
Steel rod 1.5 mm | 2
Vent tape | 1
15T servo arms | 1
Dupont housings + crimps (1-pin, 4-pin) | 3
Carbon-fibre tube 40 x 38 mm | 320 mm
M2 x 6 countersunk screws (tube) | 8
Structural epoxy | ~3 g
Thin CA | ~1 g
M2 x 6 countersunk screws (hatch) | 2
Conformal coating | ~2 ml
SKY G | SKYG SPEED 90B | REVISION C6B-8 · 2026-10-10 | USER MANUAL | 14

# POWERTRAIN

i

Motor and prop. 2207 2550 KV class 4S racing motor (e.g. 2207 2550KV: 27.9-28 mm bell, about 21.5 mm body, 33.5 mm with the 5 mm prop shaft, 33 g, 16 x 16 mm M3).

Prop: APC 5 x 7.5E fixed thin-electric pusher (LP05075E, 5 mm bore, hub 12.7 x 7.1 mm, 30,000 rpm rating), rpm-governed at 29,500.

Throttle cap. A 5-inch prop is rated about 30,000 rpm. On a full 4S pack the unloaded prop would exceed it at full throttle, so the flight controller caps the throttle at

70 %. Never raise it, and inspect the blades after every thrust-stand run and flying day.

rpm governor (open item). This version is designed around a governor that holds the prop at 29,500 rpm, which lets it use the full rated rpm in level flight.

ArduPilot's governor script does not run on the F405 flight controller, so until an H7 flight controller or a governing ESC is fitted the throttle cap above applies and the

top speed is about 63 m/s; the 80–90 m/s stages need the governor.

Battery. Tattu R-Line 4S 650 75C (60 x 31 x 21 mm, 74 g); XT30. Full throttle in bursts of ≤ 10 s, then ≥ 30 s at low throttle: the ESC lives on its thermal mass. Static thrust in

the model: 1064 g at 51 A; confirm on a thrust stand before the first flight.

SKY G | SKYG SPEED 90B | REVISION C6B-8 · 2026-10-10 | USER MANUAL | 15

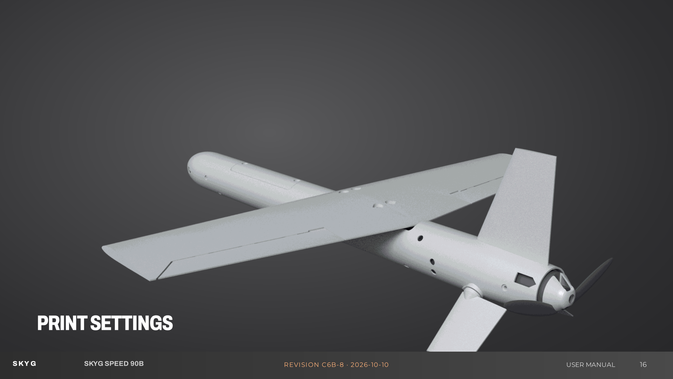
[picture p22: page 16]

# PRINTSETTINGS

SKY G | SKYG SPEED 90B | REVISION C6B-8 · 2026-10-10 | USER MANUAL | 16

# PRINTSETTINGS

i

Filament per part (no glass skin): PLA-CF wing halves (2 walls), PETG-CF ailerons, equipment tray, tail coupler, nut bars, hatch lips, duct inserts, motor plate and

spinner; PETG camera noses, hatch cover and GPS carrier (radio windows: never carbon-filled filament there); ASA tail module and fin (motor heat; the fin carries the

receiver antenna); PETG-CF tail panels and servo horns. 0.4 mm hardened-steel nozzle, 0.20 mm layers; every part fits both the H2S and the H2D build volume (340 ×

320 × 325 mm).

GENERAL GUIDELINES

- Fuselage, nose and hatch shells: 2 walls, 30 % lightning infill (it only grows under top surfaces: at 0 % the solid bosses and bridges print hollow and their tops collapse).
- Wing halves: PLA-CF, 2 walls, 8 % gyroid. Ailerons: PETG-CF, 1 wall, 5 % gyroid.
- Tail panels: 2 walls, 10 % gyroid. Fin: 2 walls, 15 %.
- Filament per part: see the parts list (PLA-CF, PETG-CF, PETG, ASA, PLA). CF filaments need a hardened-steel nozzle; ASA an enclosed printer.
- Tall standing parts: 5 mm brim, slow outer wall, enclosure door closed.

SUPPORTS: OFF

Every part is designed to print without supports in the orientation shown, and checked on the slicer's own G-code with these settings: nothing is printed over air and no bridge

is longer than 10 mm. Keep supports switched off and use the supplied .3mf files (they carry the settings). The downloads hold ONE set of Bambu Studio projects for the H2S

and the H2D: no G-code inside (G-code only fits the printer it was sliced for), tree supports on (auto). Open, select your printer, slice, print. Check the top of the aileron's torque-

rod bore on the first aileron.

SKY G | SKYG SPEED 90B | REVISION C6B-8 · 2026-10-10 | USER MANUAL | 17

# PRINTSETTINGS

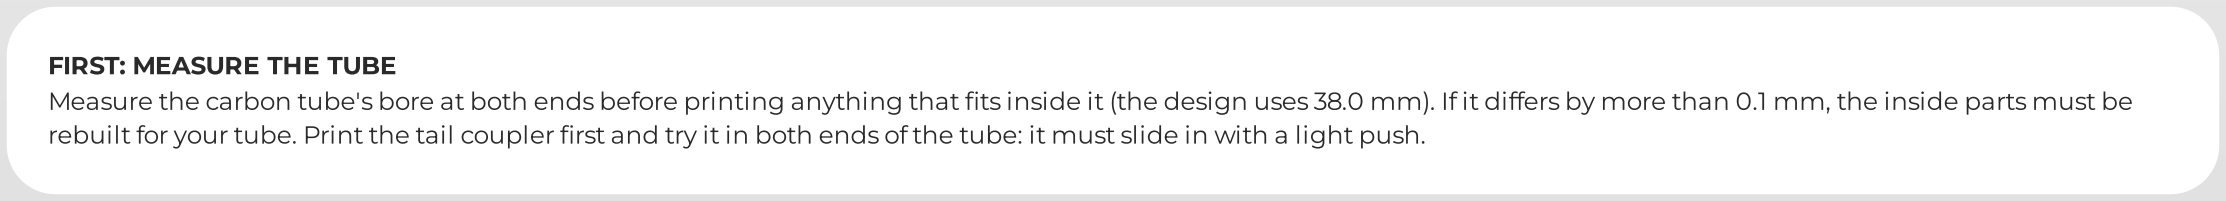
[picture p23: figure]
FIRST: MEASURE THE TUBE

Measure the carbon tube's bore at both ends before printing anything that fits inside it (the design uses 38.0 mm). If it differs by more than 0.1 mm, the inside parts must be

rebuilt for your tube. Print the tail coupler first and try it in both ends of the tube: it must slide in with a light push.

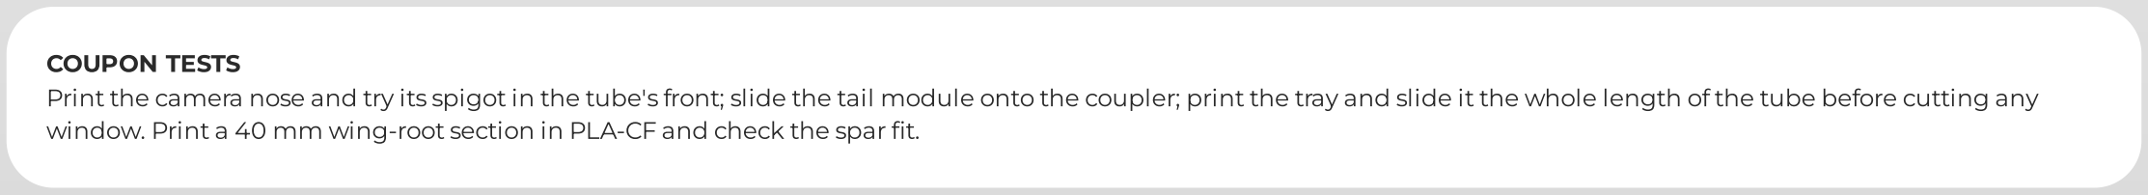
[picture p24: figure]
COUPON TESTS

Print the camera nose and try its spigot in the tube's front; slide the tail module onto the coupler; print the tray and slide it the whole length of the tube before cutting any

window. Print a 40 mm wing-root section in PLA-CF and check the spar fit.

SKY G | SKYG SPEED 90B | REVISION C6B-8 · 2026-10-10 | USER MANUAL | 18

# PARTSLIST

PART | MATERIAL | MASS
N0M NOSE (MICRO FPV) | PETG | 13.9 g
N0P NOSE (PI CAMERA) | PETG | 13.2 g
N0O NOSE (DJI O4) | PETG | 14.7 g
F3 TAIL MODULE | ASA | 14.3 g
HF FRONT HATCH | PETG | 4.3 g
FN FIN | ASA | 6.7 g
VTX SHELF (N0M) | PETG | 0.8 g
HG GPS CARRIER | PETG | 1.1 g
NB1 WING-NUT BAR FRONT | PETG-CF | 1.2 g
NB2 WING-NUT BAR REAR | PETG-CF | 1.3 g
HL1 HATCH LIP FRONT | PETG-CF | 0.9 g
HL2 HATCH LIP REAR | PETG-CF | 0.9 g
PART | MATERIAL | MASS
WR WING HALF RIGHT | PLA-CF | 47.2 g
WL WING HALF LEFT | PLA-CF | 47.3 g
AR AILERON RIGHT | PETG-CF | 4.0 g
AL AILERON LEFT | PETG-CF | 3.8 g
SR TAIL PANEL RIGHT | PETG-CF | 5.2 g
SL TAIL PANEL LEFT | PETG-CF | 5.2 g
M1 MOTOR PLATE | PETG-CF | 2.1 g
SP SPINNER | PETG-CF | 1.6 g
TR EQUIPMENT TRAY | PETG-CF | 17.8 g
TC TAIL COUPLER | PETG-CF | 8.5 g
CW COUNTERSUNK WASHER (PRINT 14) | PETG-CF | 0.1 g
WF WING-WINDOW FILLER | PETG-CF | 1.4 g

One aircraft with the N0M nose: 238 g printed. Only one camera nose is needed; the others

are options.

SKY G | SKYG SPEED 90B | REVISION C6B-8 · 2026-10-10 | USER MANUAL | 19

# PARTSORIENTATION

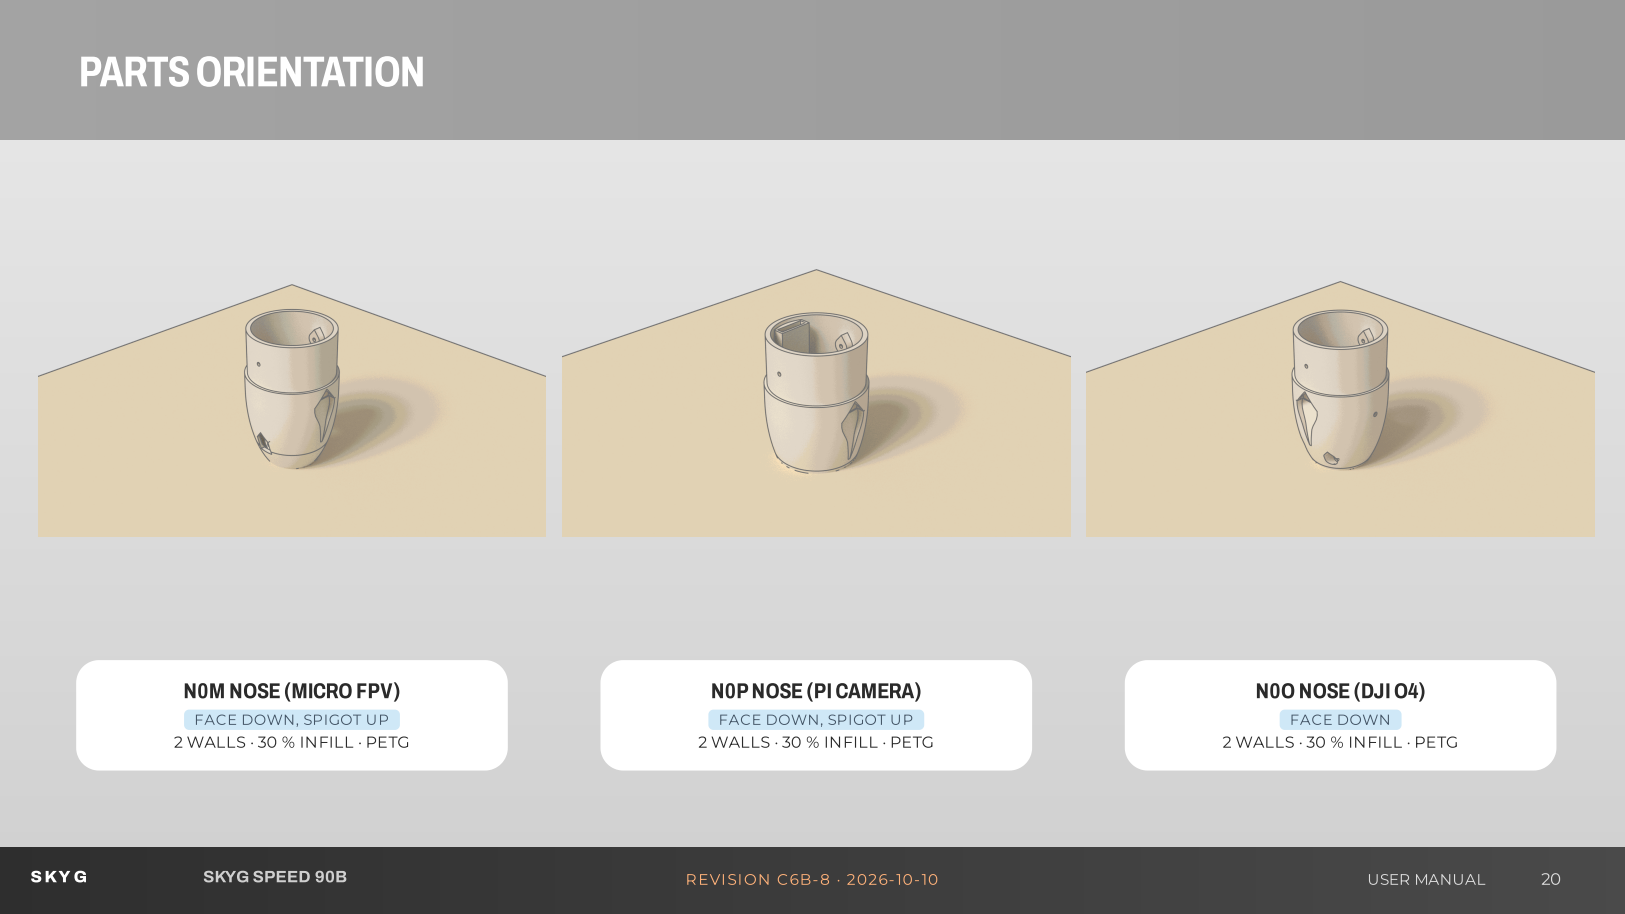
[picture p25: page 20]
N0PNOSE (PICAMERA); N0O NOSE (DJIO4); FACE DOWN; SKY G; SKYG SPEED 90B; REVISION C6B-8 · 2026-10-10; USER MANUAL

N0M NOSE (MICRO FPV)

FACE DOWN, SPIGOT UP

2 WALLS · 30 % INFILL · PETG

# PARTSORIENTATION

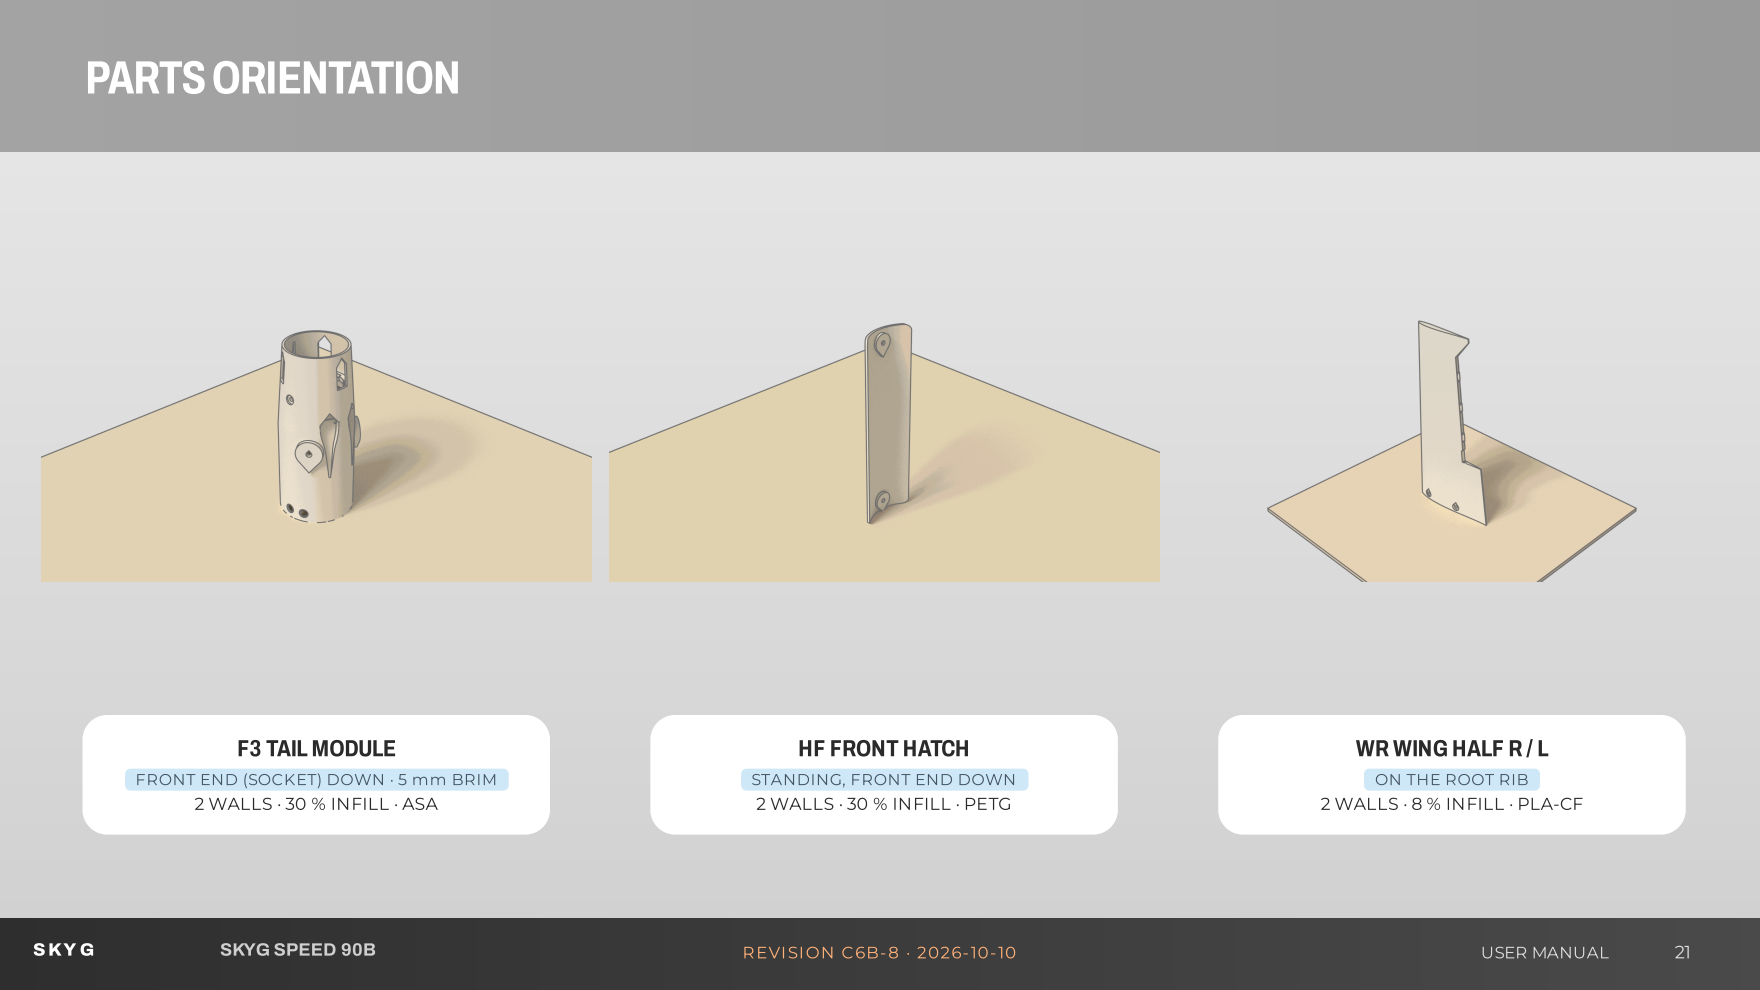
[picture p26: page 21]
F3 TAIL MODULE; SKY G; SKYG SPEED 90B; REVISION C6B-8 · 2026-10-10; USER MANUAL

HF FRONT HATCH

WR WING HALF R / L

FRONT END (SOCKET) DOWN · 5 mm BRIM

STANDING, FRONT END DOWN

ON THE ROOT RIB

2 WALLS · 30 % INFILL · ASA

2 WALLS · 30 % INFILL · PETG

2 WALLS · 8 % INFILL · PLA-CF

# PARTSORIENTATION

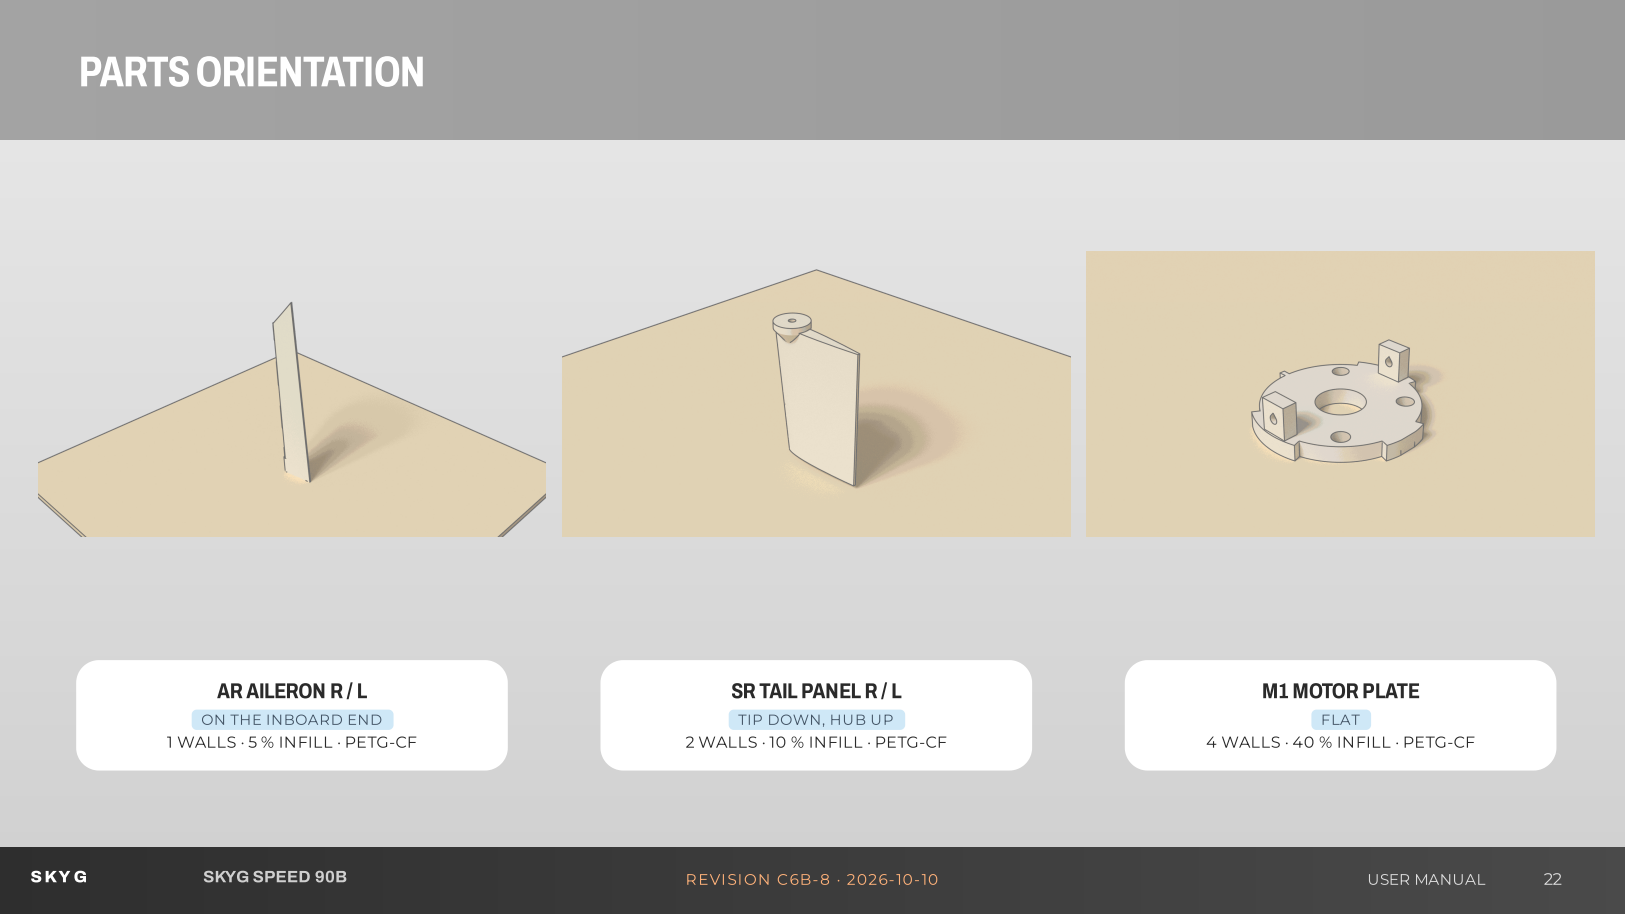
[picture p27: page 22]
AR AILERON R / L; M1 MOTOR PLATE; FLAT; SKY G; SKYG SPEED 90B; REVISION C6B-8 · 2026-10-10; USER MANUAL

SR TAIL PANEL R / L

ON THE INBOARD END

TIP DOWN, HUB UP

1 WALLS · 5 % INFILL · PETG-CF

2 WALLS · 10 % INFILL · PETG-CF

4 WALLS · 40 % INFILL · PETG-CF

# PARTSORIENTATION

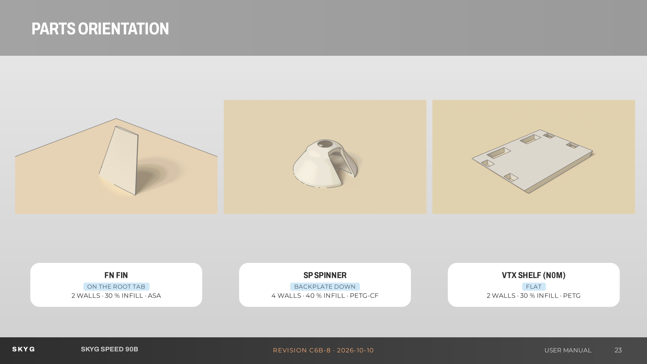
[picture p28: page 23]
FN FIN; SPSPINNER; BACKPLATE DOWN; VTX SHELF (N0M); FLAT; SKY G; SKYG SPEED 90B; REVISION C6B-8 · 2026-10-10; USER MANUAL

ON THE ROOT TAB

2 WALLS · 30 % INFILL · ASA

4 WALLS · 40 % INFILL · PETG-CF

2 WALLS · 30 % INFILL · PETG

# PARTSORIENTATION

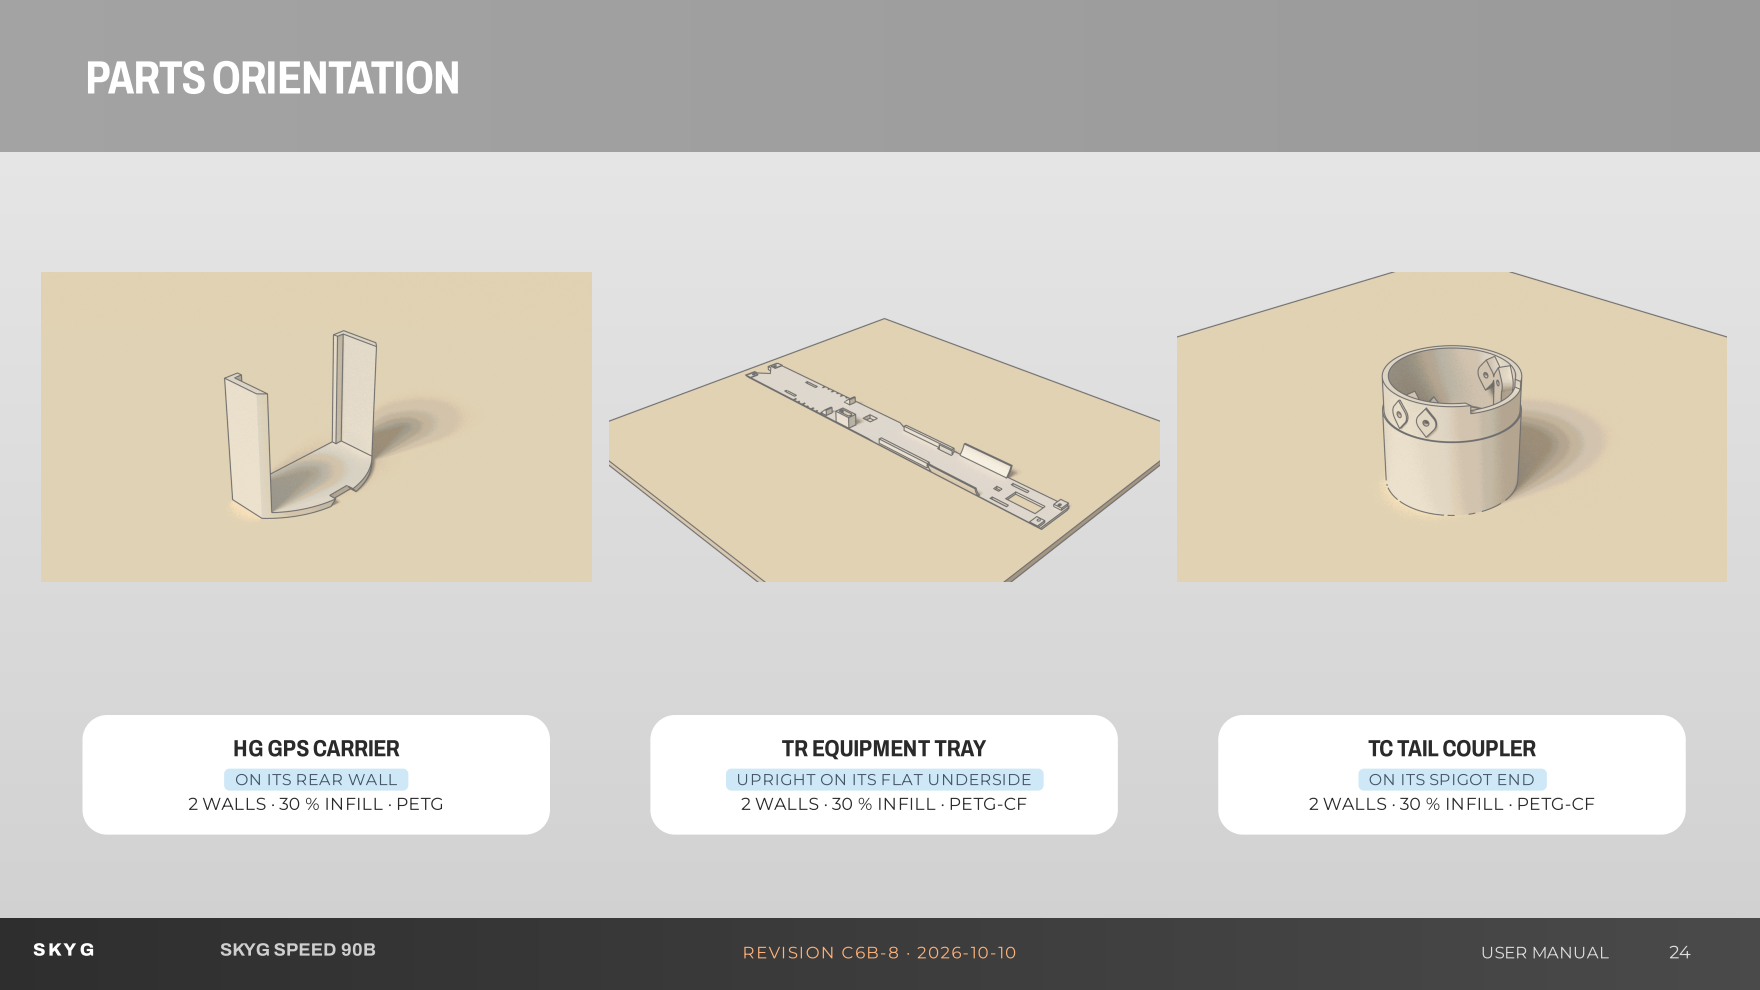
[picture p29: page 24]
HG GPSCARRIER; SKY G; SKYG SPEED 90B; REVISION C6B-8 · 2026-10-10; USER MANUAL

TR EQUIPMENT TRAY

TC TAIL COUPLER

ON ITS REAR WALL

UPRIGHT ON ITS FLAT UNDERSIDE

ON ITS SPIGOT END

2 WALLS · 30 % INFILL · PETG

2 WALLS · 30 % INFILL · PETG-CF

# PARTSORIENTATION

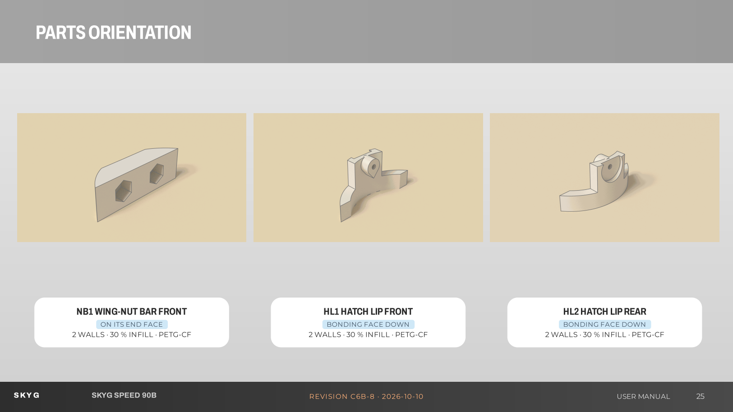
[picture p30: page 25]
HL1 HATCH LIPFRONT; HL2HATCH LIPREAR; SKY G; SKYG SPEED 90B; REVISION C6B-8 · 2026-10-10; USER MANUAL

NB1 WING-NUT BAR FRONT

ON ITS END FACE

BONDING FACE DOWN

2 WALLS · 30 % INFILL · PETG-CF

# PARTSORIENTATION

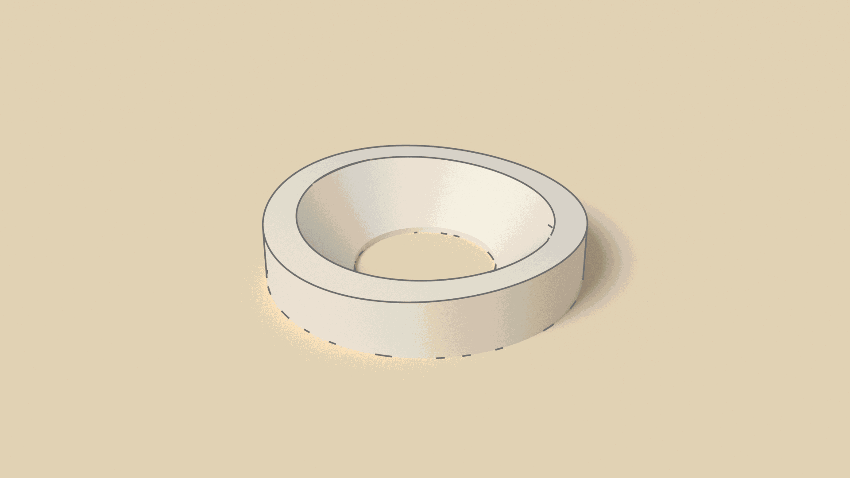
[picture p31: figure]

### CW COUNTERSUNKWASHER (PRINT 14)

FLAT FACE DOWN

2 WALLS · 30 % INFILL · PETG-CF

SKY G | SKYG SPEED 90B | REVISION C6B-8 · 2026-10-10 | USER MANUAL | 26

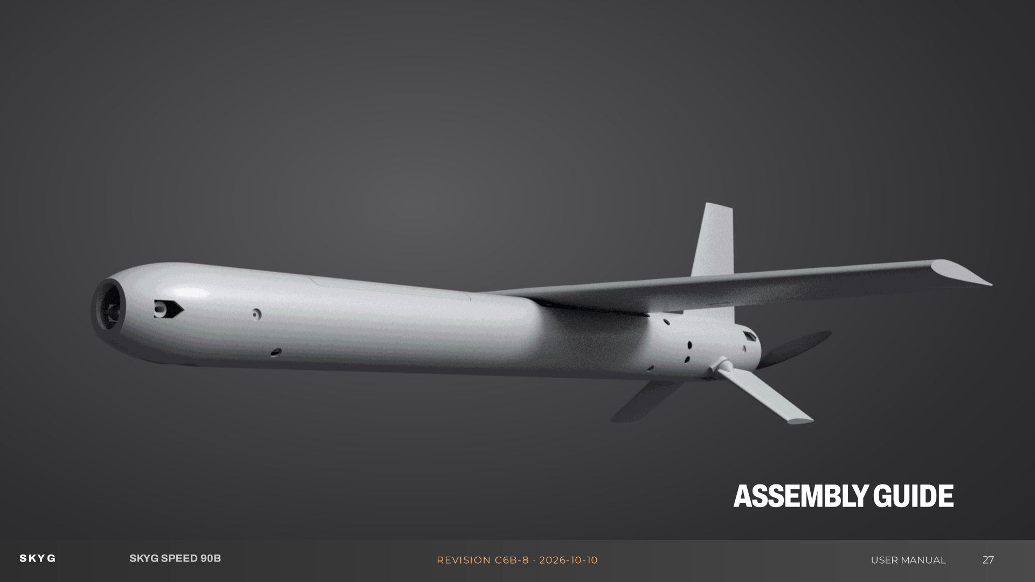
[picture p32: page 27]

# ASSEMBLYGUIDE

SKY G | SKYG SPEED 90B | REVISION C6B-8 · 2026-10-10 | USER MANUAL | 27

# CARBONTUBE

i

Cut the 40 × 38 mm carbon tube to 320 mm. Print

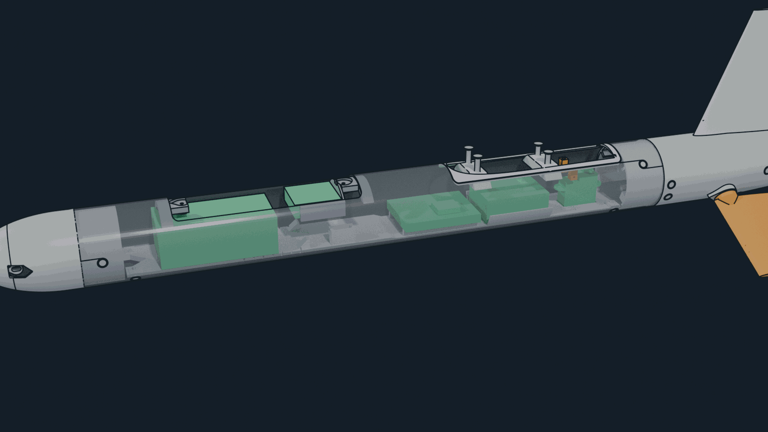
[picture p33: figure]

the 1:1 cutting template (two A4 pages, 100 % scale:

check its 100 mm bar), cut the strip out, wrap it

round the tube with its ends on the tube ends and

the TOP line along the top, tape it. Cut every

window inside the red lines with a diamond disc

and file to the line; drill the 2.2 mm holes. FFP3

mask, eye protection, vacuum at the disc or cut wet.

Seal every cut edge and hole with thin CA: carbon

conducts, a bare edge can cut a wire's insulation

and short it.

DIAMOND DISC

SKY G | SKYG SPEED 90B | REVISION C6B-8 · 2026-10-10 | USER MANUAL | 28

# CARBONTUBE

i

Scuff the bonding areas inside the tube (120 grit)

and clean them with alcohol. With structural epoxy

bond: the tail coupler TC into the aft end, its sleeve

over the whole ring behind the wing window, and

fix it with 2 × countersunk M2 × 6 in washers at the

sides (they hold it aligned while the epoxy cures

and back the bond up); the two wing-nut bars

NB1/NB2 across the wing-bay window (in through

the window, turned under its edges, pocket down);

the hatch lips HL1/HL2 under the front hatch

opening's ends (their screw bosses down, centred

under the opening). Let it cure before the tray goes

in.

EPOXY

SKY G | SKYG SPEED 90B | REVISION C6B-8 · 2026-10-10 | USER MANUAL | 29

# EQUIPMENTTRAY

i

Build the tray on the bench: the ESC on its rails, the

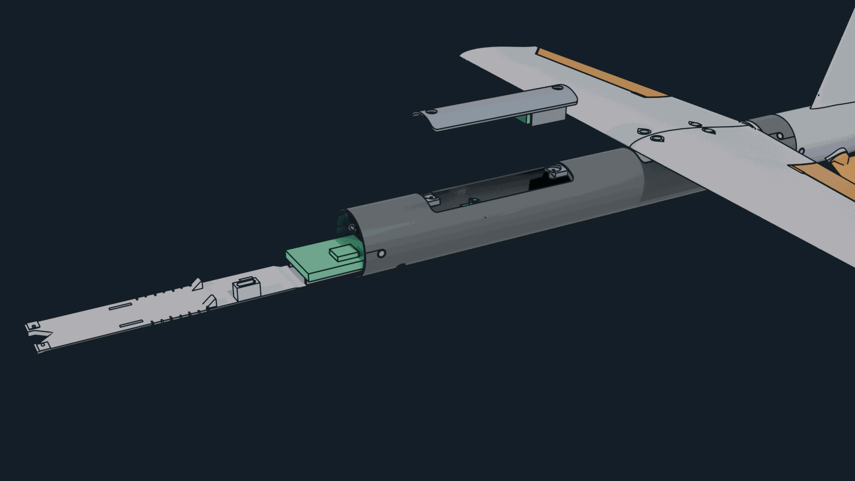
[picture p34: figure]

FC stack, receiver and aileron servo, all wiring as on

the next pages. Take the camera nose off, push the

tray into the tube from the front until its screw holes

line up, and fix it with 4 × countersunk M2 × 6 screws

through the tube (do not overtighten: they thread

into printed pillars). Every external screw (the tube,

the tail joint, the motor plate) sits flush in a printed

countersunk washer (CW) pressed into its 5 mm

hole: print 14, push one into each hole before the

screw. To service the equipment: battery out, nose

off, unhook the aileron pushrods, unplug the tail-

module plugs, four screws out, slide the tray

forward.

COUNTERSUNK M2 × 6

SKY G | SKYG SPEED 90B | REVISION C6B-8 · 2026-10-10 | USER MANUAL | 30

# FUSELAGEASSEMBLY

i

The camera nose plugs into the tube's front (its

spigot is sized to the tube's bore) with 2 ×

countersunk M2 × 6, flush in their printed washers,

into its bosses; the tail module slides onto the tail

coupler's spigot (the four pads on the coupler slide

in the grooves inside the module) and is held by 4 ×

countersunk M2 × 6 (two each side: at the side and

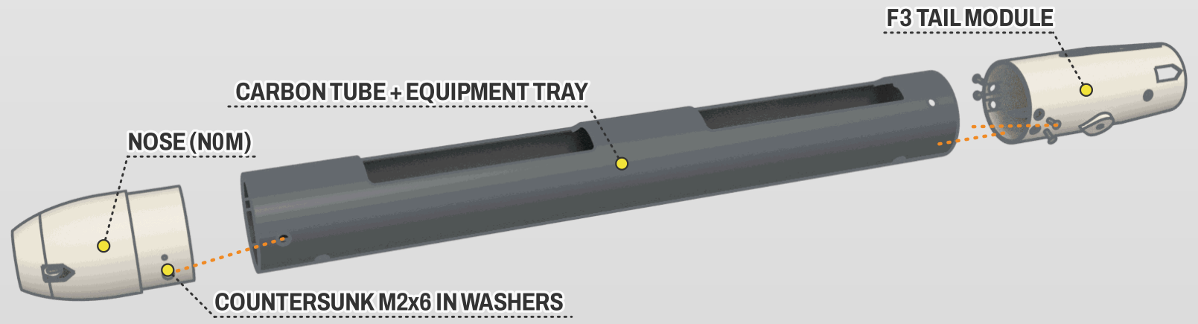
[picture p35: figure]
NOSE((N0M)); CARBONTUBE++EQUIPMENTTRAY; F3 TAILMODULE; COUNTERSUNKM2x6 INWASHERS

25° below it), each in a printed washer in its 5 mm

hole, as on the tube. Nothing is glued: both

modules come off for service. They must slide on by

hand; if the bore is tight, sand the spigot, never

force it.

M2 × 6 SCREWS

SKY G | SKYG SPEED 90B | REVISION C6B-8 · 2026-10-10 | USER MANUAL | 31

# WINGASSEMBLY

i

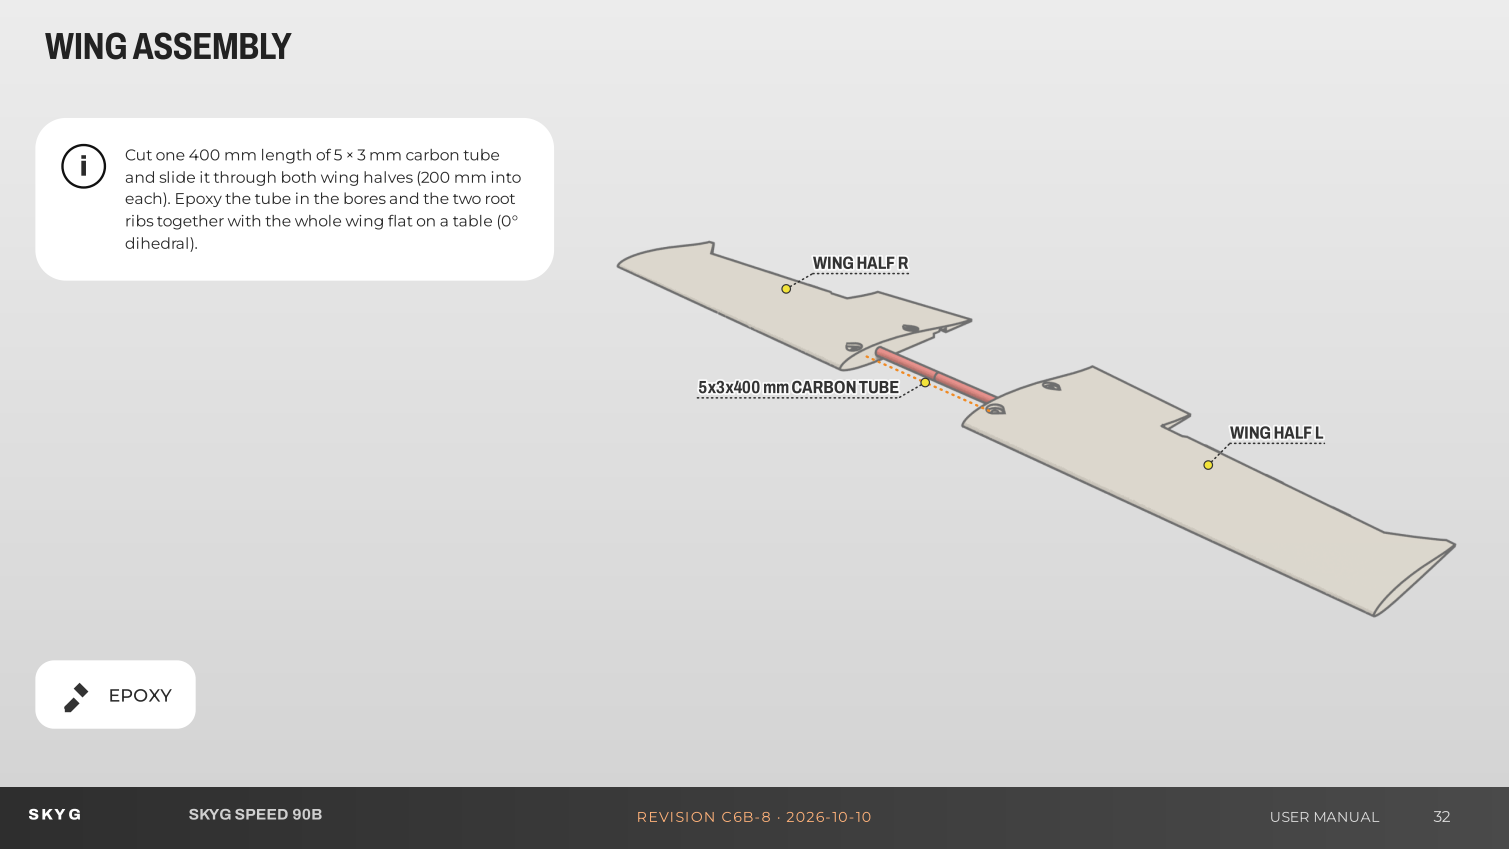
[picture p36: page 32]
WWIINNGGHHAALLFF RR; WWIINNGGHHAALLFF LL; 55xx33xx440000 mmmmCCAARRBBOONNTTUUBBEE; dihedral).; EPOXY; SKY G; SKYG SPEED 90B; REVISION C6B-8 · 2026-10-10; USER MANUAL

Cut one 400 mm length of 5 × 3 mm carbon tube

and slide it through both wing halves (200 mm into

each). Epoxy the tube in the bores and the two root

ribs together with the whole wing flat on a table (0°

# WINGASSEMBLY

i

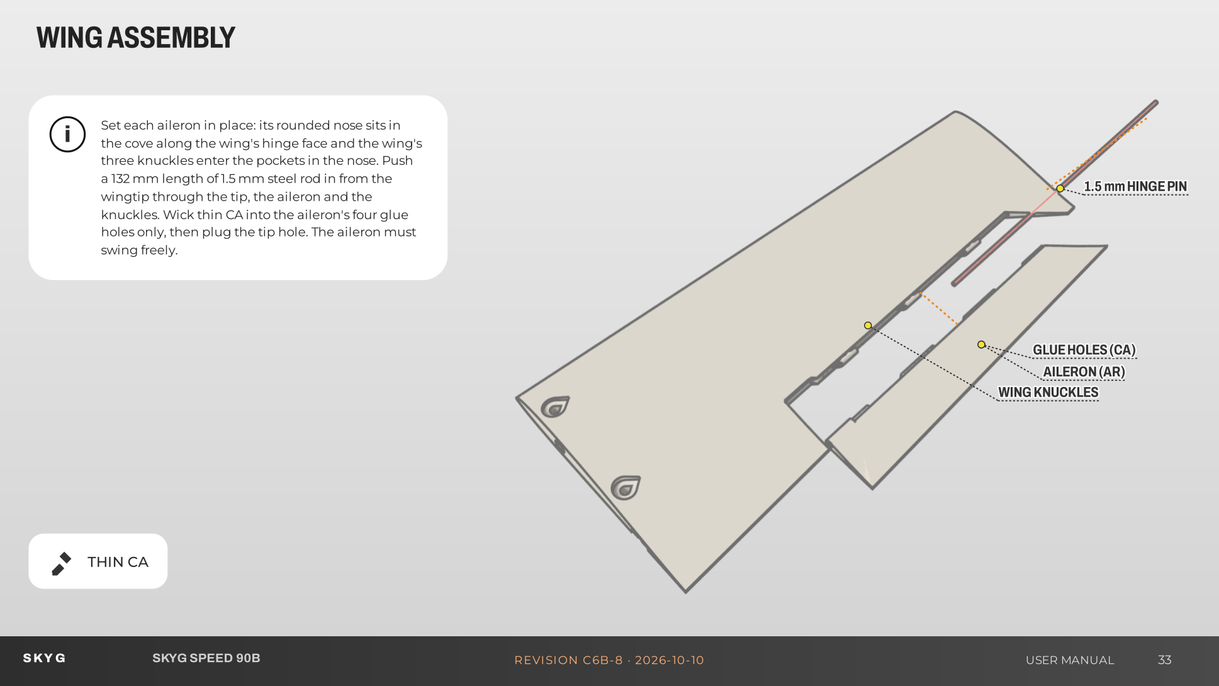
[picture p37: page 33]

## AILERON(AR)

11..55 mmmmHHIINNGGEEPPIINN

WWIINNGGKKNNUUCCKKLLEESS

GLUEHOLES(CA)

Set each aileron in place: its rounded nose sits in

the cove along the wing's hinge face and the wing's

three knuckles enter the pockets in the nose. Push

a 132 mm length of 1.5 mm steel rod in from the

wingtip through the tip, the aileron and the

knuckles. Wick thin CA into the aileron's four glue

holes only, then plug the tip hole. The aileron must

swing freely.

THIN CA

SKY G | SKYG SPEED 90B | REVISION C6B-8 · 2026-10-10 | USER MANUAL | 33

# WINGASSEMBLY

i

22..00 MMMMTTOORRQQUUEERROODD

HORN+PIN

FLATTEDENDINTOTHEKNUCKLE(EPOXY)

Bend a 12 mm horn down at one end of each 2.0

mm rod with a 5.5 mm pin outboard at its tip, and

file a 0.3 mm flat on the last 9 mm of the straight

end, opposite the horn. Push it in from the root face

until the flat enters the D-bore of the aileron's root

knuckle; epoxy the end and hold the aileron 3°

trailing edge up while it cures.

EPOXY

SKY G | SKYG SPEED 90B | REVISION C6B-8 · 2026-10-10 | USER MANUAL | 34

# TAILMODULE

i

## TTAAIILLPPAANNEELLRR

## TTAAIILLPPAANNEELLLL

SHAFT+COLLARHORN

33//3322iinnBBRRAASSSSBBUUSSHHIINNGGSS

Press a 10 mm brass bushing into each side boss of

F3. Epoxy a 2.5 mm steel shaft 35 mm into each tail

panel's root bore. From the open front of F3, push

each shaft through its bushing and fit the wheel-

collar horn with its 8 mm brass plate standing along

the panel's normal (not pointing forward), 0.5 mm

end play, set screw on a filed flat.

EPOXY

SKY G | SKYG SPEED 90B | REVISION C6B-8 · 2026-10-10 | USER MANUAL | 35

# TAILMODULE

i

Screw the motor to the M1 plate on the bench with

its 4 × M3 (heads on the plate's front face). Slide the

plate into the rear of F3 until it sits on the seat ring,

its two side lugs in the ring's pockets and its edge

notches on the cooling windows, then fix it with 2 ×

countersunk M2 × 6 through the tail module's sides

into the lugs, each in a printed washer in its

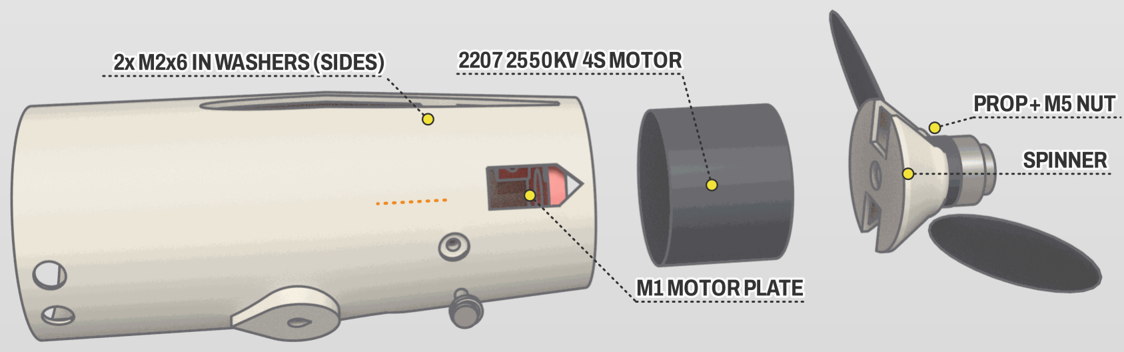
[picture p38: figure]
M1MOTORPLATE; 22072550KV 4SMOTOR; SPINNER; PROP+M5 NUT; 2xM2x6 INWASHERS(SIDES)

counterbore, flush (no glue: the plate comes out for

a different motor). Fit the spinner backplate, the

prop (APC 5 x 7.5E fixed thin-electric pusher

(LP05075E, 5 mm bore, hub 12.7 x 7.1 mm, 30,000

rpm rating), rpm-governed at 29,500) and the thin

M5 nut.

M2 × 6 SCREWS

SKY G | SKYG SPEED 90B | REVISION C6B-8 · 2026-10-10 | USER MANUAL | 36

# TAILMODULE

## 1155TTAARRMM((HHOOLLEERREEAAMMEEDD11..22mmmm))

i

Stand both ES9052MD servos through the cut-outs

in the F3 floor on foam tape on the bottom skin, a

strap over them, output at the aft end, leads along

the side walls. One-sided 15T arm pointing

outboard; file a 0.3 mm flat on the inboard end of

each 2.5 mm stabilator shaft and epoxy the printed

horn (THR / THL) on it, arm along the panel's

normal. Drill the servo arm's 6.7 mm hole 1.1 mm

and ream it by hand with a 1.2 mm bit (and the

horn's hole the same): the wire must turn with no

play. 1.2 mm Z-bend pushrod: Z-bend in the arm,

90° L-bend at the horn end pushed outboard

through the horn's reamed hole, snap-on keeper on

the protruding end (unclip it to take the tail

module off). Free play at each panel trailing edge <=

0.2 mm. Check both panels move freely through

±20°.

SERVO TAPE

SKY G | SKYG SPEED 90B | REVISION C6B-8 · 2026-10-10 | USER MANUAL | 37

# TAILMODULE

i

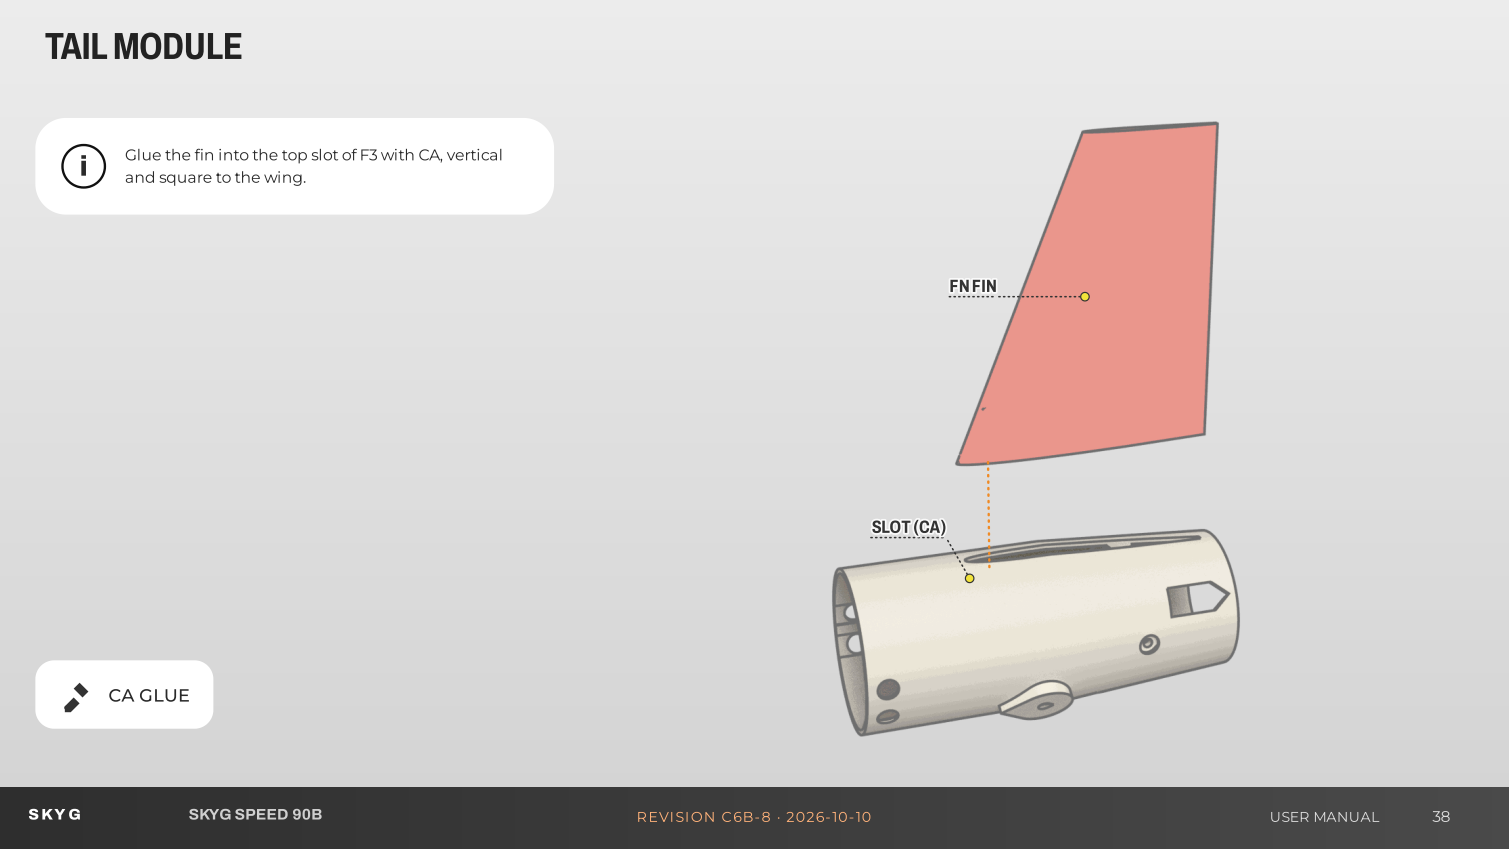
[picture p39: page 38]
FFNNFFIINN; SSLLOOTT((CCAA)); CA GLUE; SKY G; SKYG SPEED 90B; REVISION C6B-8 · 2026-10-10; USER MANUAL

Glue the fin into the top slot of F3 with CA, vertical

and square to the wing.

# FUSELAGEASSEMBLY

i

Bond the printed GPS carrier (HG) under the rear of

the PETG hatch cover (the GPS's radio window:

never paint it with metallic paint). Put foam tape on

the carrier's two side lips and slide the TBS M10Q

GPS in from the front, patch up, onto the lips

against the rear wall: it is carried from below, with

nothing but air and the cover between its patch

and the sky. The cover is held by two flush

countersunk M2 × 6 screws in steel cup washers, one

at each end, into the bosses under the bonded lips

(no magnets: suction and the GPS's weight would

lift them at speed). Leave a slack loop in the GPS

lead so the cover lifts off. With the cover off you

reach the battery, its XT30 and the FC's USB-C

socket (left side, beside the GPS lead): plug the

laptop in there for setup, parameters and logs.

FOAM TAPE

SKY G | SKYG SPEED 90B | REVISION C6B-8 · 2026-10-10 | USER MANUAL | 39

# FUSELAGEASSEMBLY

i

Lower the pack through the hatch against its rear

stop (two ribs on the floor), then slide it forward

under the tube until its rear edge is at the tick the

balance table gives (ticks every 5 mm on the floor

edges); one strap through the slots. The XT30 pair

lies behind the pack under the GPS and unplugs

through the hatch. To take the pack out, slide it

back to the stop first.

VELCRO STRAP

SKY G | SKYG SPEED 90B | REVISION C6B-8 · 2026-10-10 | USER MANUAL | 40

# EQUIPMENT

i

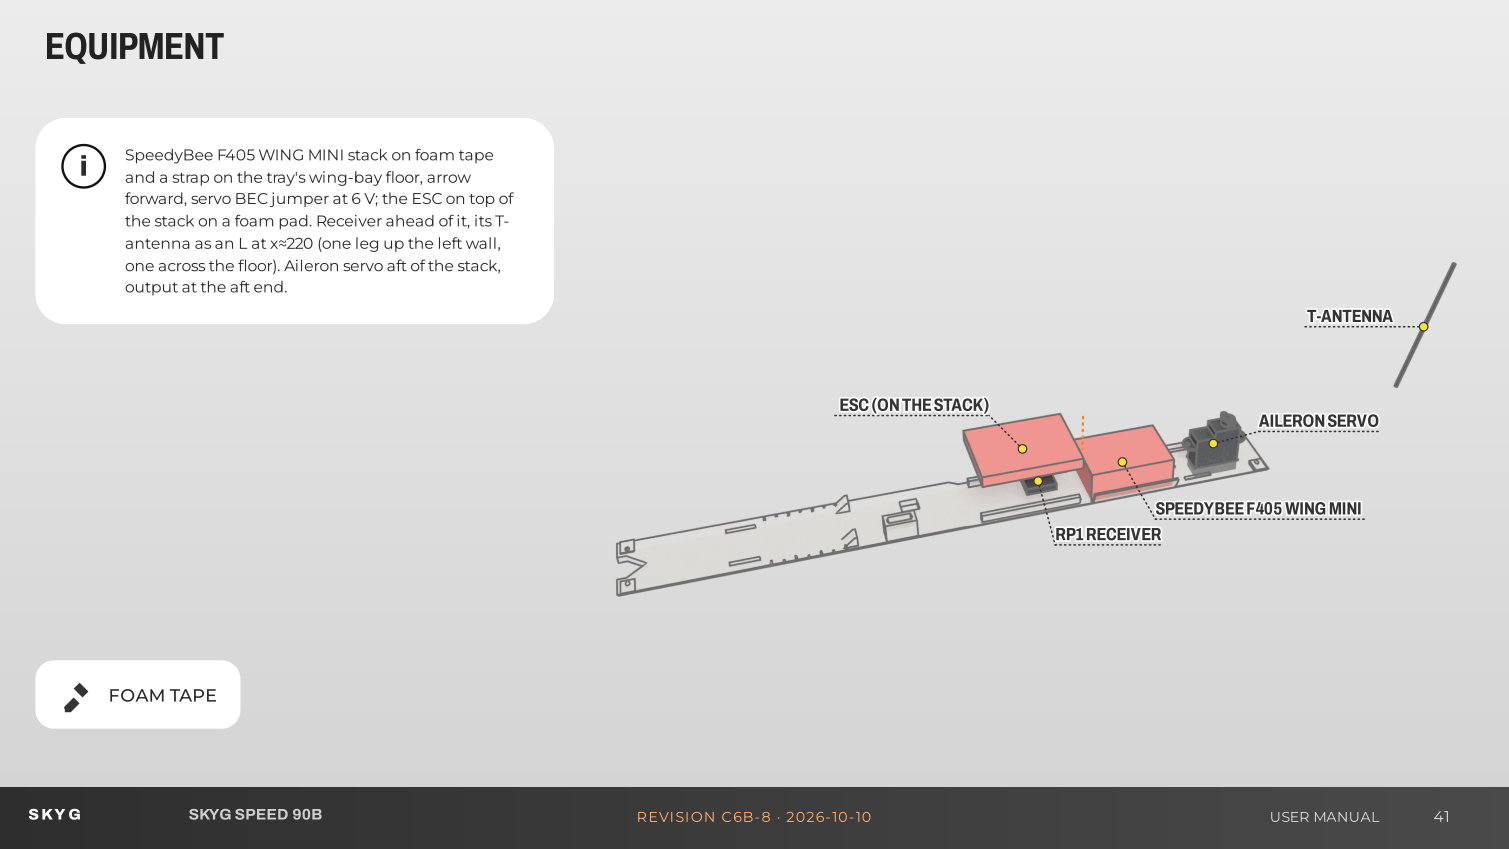
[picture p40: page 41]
SSPPEEEEDDYYBBEEEEFF440055 WWIINNGGMMIINNII; EESSCC((OONNTTHHEESSTTAACCKK)); RRPP11RREECCEEIIVVEERR; TT--AANNTTEENNNNAA; AAIILLEERROONNSSEERRVVOO; FOAM TAPE; SKY G; SKYG SPEED 90B; REVISION C6B-8 · 2026-10-10; USER MANUAL

SpeedyBee F405 WING MINI stack on foam tape

and a strap on the tray's wing-bay floor, arrow

forward, servo BEC jumper at 6 V; the ESC on top of

the stack on a foam pad. Receiver ahead of it, its T-

antenna as an L at x≈220 (one leg up the left wall,

one across the floor). Aileron servo aft of the stack,

output at the aft end.

# EQUIPMENT

i

ES9052MD aileron servo standing through the

wing-bay floor on foam tape; two-sided 15T arm.

Each torque rod has one 90° bend (the horn leg, 6

mm from the centreline); epoxy the printed horn

(AHR / AHL) on the leg, 4 mm deep. Drill the arm's

4.3 mm holes 1.1 mm and ream them by hand with

a 1.2 mm bit (and both horns' holes): the wire must

turn with no play. Each horn connects to the arm

with a 1.2 mm Z-bend pushrod: Z-bend in the arm,

90° L-bend pushed inboard through the horn's

reamed hole, snap-on keeper on the protruding

end. Check: with the servo powered, each aileron

trailing edge moves <= 0.2 mm (free play lowers

aileron flutter to about 33 m/s). Set both ailerons 3°

trailing edge up at servo neutral. No play at either

end.

Z-BENDS

SKY G | SKYG SPEED 90B | REVISION C6B-8 · 2026-10-10 | USER MANUAL | 42

# EQUIPMENT

i

ESC flat on its foam tape at the bottom of the wing

bay, receiver on top of it, FC stack 5 mm behind it

(servo header row on the right). Battery lead (14

AWG) from the XT30 over the ESC and down the

gap to the FC power board's BAT pads; 14 AWG ESC

feed from its ESC pads up onto the ESC; ESC signal

(M1, GND, TLM) and receiver lead up the gap to the

FC; motor phases up the gap, over the FC's left half

to the MR30; the ELRS coax under the wing-nut

bars to the u.FL joint ahead of the tail joint and up

into the fin. Cut lengths and lanes: Electrical

Integration manual. Unplug the MR30, the u.FL

joint and the servo plugs before pulling the tail

module.

HEAT SHRINK

SKY G | SKYG SPEED 90B | REVISION C6B-8 · 2026-10-10 | USER MANUAL | 43

# CAMERANOSE

i

Slide the 19 mm camera in from the open rear until

the lens reaches the face; 2 × M2 × 8 pan head + 2 ×

M2 washer (5 mm OD) through the side seats, lens

flush, tilt 0–10° up. Fix the VTX to the printed VTX

shelf (foam tape + zip tie through its slots), slide the

shelf in from the rear onto its two rails and glue it;

video antenna in the two clips on the right wall.

Plug the one lead at the nose joint. Dome noses:

glue the printed dome ring 3 mm into the front of

the tube, then fit the clear dome over its lip with

canopy glue (no CA).

FOAM TAPE

SKY G | SKYG SPEED 90B | REVISION C6B-8 · 2026-10-10 | USER MANUAL | 44

# CAMERANOSE

i

DJI O4 option, in this order: (1) snap the video

antenna into its two clips on the left wall, from the

rear; (2) slide the camera in its mount in from the

back and clamp it with 4 × M2 × 5 through the side

slots (at most 3.1 mm into the mount), lens flush; (3)

plug the coax and the 3-in-1 lead into the module

and slide the module edge-first into the duct insert

(DT) until it stops, foam strip in the top groove; (4)

slide the insert in through the spigot until its two

notches stop on the joint-screw bosses. The tray

holds it once the nose is on the tube. Cooling air

comes in through the belly NACA and rises over the

insert's sill before it reaches the module: never tape

the module's faces.

M2 × 5 SCREWS

SKY G | SKYG SPEED 90B | REVISION C6B-8 · 2026-10-10 | USER MANUAL | 45

# FINALASSEMBLY

i

Glue the printed window filler (WF) under the wing

root (epoxy), centred, with the wing on the tube so it

lines up with the window. Push an M3 nut up into

each of the bonded nut bars' pockets (two per bar).

Set the wing into the tube's rectangular window

(the filler plugs in) and bolt it with the steel

countersunk screws in steel cup washers (flush in

the recesses), two at each station, one in each wing

half (each half is clamped on its own, off the glued

seam): M3 × 16 at the front, M3 × 12 at the rear; they

pull the nut bars up against the tube from inside.

Snug them with a small driver, do not overtighten

(the nut bars are printed).

STEEL SCREWS

SKY G | SKYG SPEED 90B | REVISION C6B-8 · 2026-10-10 | USER MANUAL | 46

# FINISHINGBUILD

i

Before the first flight: every control surface moves the right way (pitch up: both

panel trailing edges up; right roll: right aileron up), throws ±10° on the tail panels,

about ±10° (±3.5 mm at the trailing edge) on the ailerons, 30 % expo; the prop turns

the right way and pushes aft; failsafe set to motor off.

Balance: CG 10 mm behind the wing leading edge at the root (mark it on the wing

underside). Slide the battery to trim; for the first flight set the CG 2 mm forward. If a

heavy camera needs it, use the nose ballast cup.

SKY G | SKYG SPEED 90B | REVISION C6B-8 · 2026-10-10 | USER MANUAL | 47

# WIRINGDIAGRAM

S1 ·THROTTLE(MOTORESC)

SS33 ··AAIILLEERROONN

S4·V-TAILLEFT | S5 ·V-TAILRIGHT

FC

## RX (UART1)

GPS(UART3)

44SSPPAACCKK

## MOTOR

i

The diagram shows the flight-controller outputs and where each device sits.

Signal, power and video leads follow the routes on the wiring page of the

assembly guide; the package has this diagram as a separate large page.

PAD | FUNCTION | DEVICE
S1 | Throttle (motor ESC) | ESC (DShot300, bidirectional)
S2 | Unused | Leave empty (DShot group with S1)
S3 | Aileron | Aileron servo (ES9052MD, wing bay)
S4 | V-tail left | Left tail-panel servo (ES9052MD, tail module)
S5 | V-tail right | Right tail-panel servo (ES9052MD, tail module)
SKY G | SKYG SPEED 90B | REVISION C6B-8 · 2026-10-10 | USER MANUAL | 48

# ELECTRICAL INTEGRATION

Battery → FC power board (80 A current sensor) → ESC (motor on M1) → MR30 at the tail joint → motor. Main DC path 14 AWG (46 A on a pass, 51 A static), motor phases 16 AWG (38 A

RMS). Cable lengths are measured on the 3D harness model; the cut list adds the termination allowances and slack. Full detail, pinouts, settings and tests: the Electrical Integration

manual (PDF in the package and on the web page).

ID | CABLE | FROM | TO | AWG | CUT mm
W01 | Battery lead | XT30 female (the pack plugs in), behind the pack under… | FC power board BAT+ / BAT- pads | 14 | 125
W02 | ESC feed | FC power board ESC+ / ESC- pads | HDZero Halo 4in1 70A ESC AM32 BAT+ / BAT- pads (XT60… | 14 | 35
W03 | Motor phases, ESC side | HDZero Halo 4in1 70A ESC AM32 M1 pads (A, B, C) | MR30 female (ESC side), low on the left ahead of the… | 16 | 110
W04 | Motor phases, motor side | MR30 male | Motor phase wires (cut to 20 mm, butt-soldered + heat… | 16 | 140
W05 | ESC signal | HDZero Halo 4in1 70A ESC AM32 8-pin SH1.0 lead (only M1,… | FC S1 header (signal, GND); TLM to the R4 pad | 28 | 45
W06 | Receiver lead | RadioMaster RP1 V2 pads (5V, GND, TX, RX), on the ESC | FC receiver header (5V, GND, RX1, TX1) | 28 | 45
W07 | ELRS antenna coax | RP1 V2 u.FL | Dipole feed at the centre of the fin dipole (z 39.5) | coax | 275
W08 | GPS lead | TBS M10Q (VCC, GND, TX, RX, SDA, SCL) | FC GPS interface with compass (4V5, GND, RX3, TX3, SDA,… | 28 | 130
W09 | Video trunk (N0M nose) | Nose joint plug (camera on the nose; VTX on the nose or,… | FC pads: Vv, G, C1 (camera in), VTX (video out) | 28 | 275
W10 | Tail servo leads (L, R) | Emax ES9052MD in F3 (its stock lead) | JR plug pair lying flat beside the aileron servo | 26 | stock
W12 | Tail servo extensions (L, R) | JR plug pair (beside the aileron servo) | FC S4 (left) / S5 (right) | 26 | stock
W11 | Aileron servo lead | Emax ES9052MD lead (stock), aileron servo in the wing bay | FC S3 header | 26 | stock
SKY G | SKYG SPEED 90B | REVISION C6B-8 · 2026-10-10 | USER MANUAL | 49

# ELECTRICAL:POWERANDROUTING

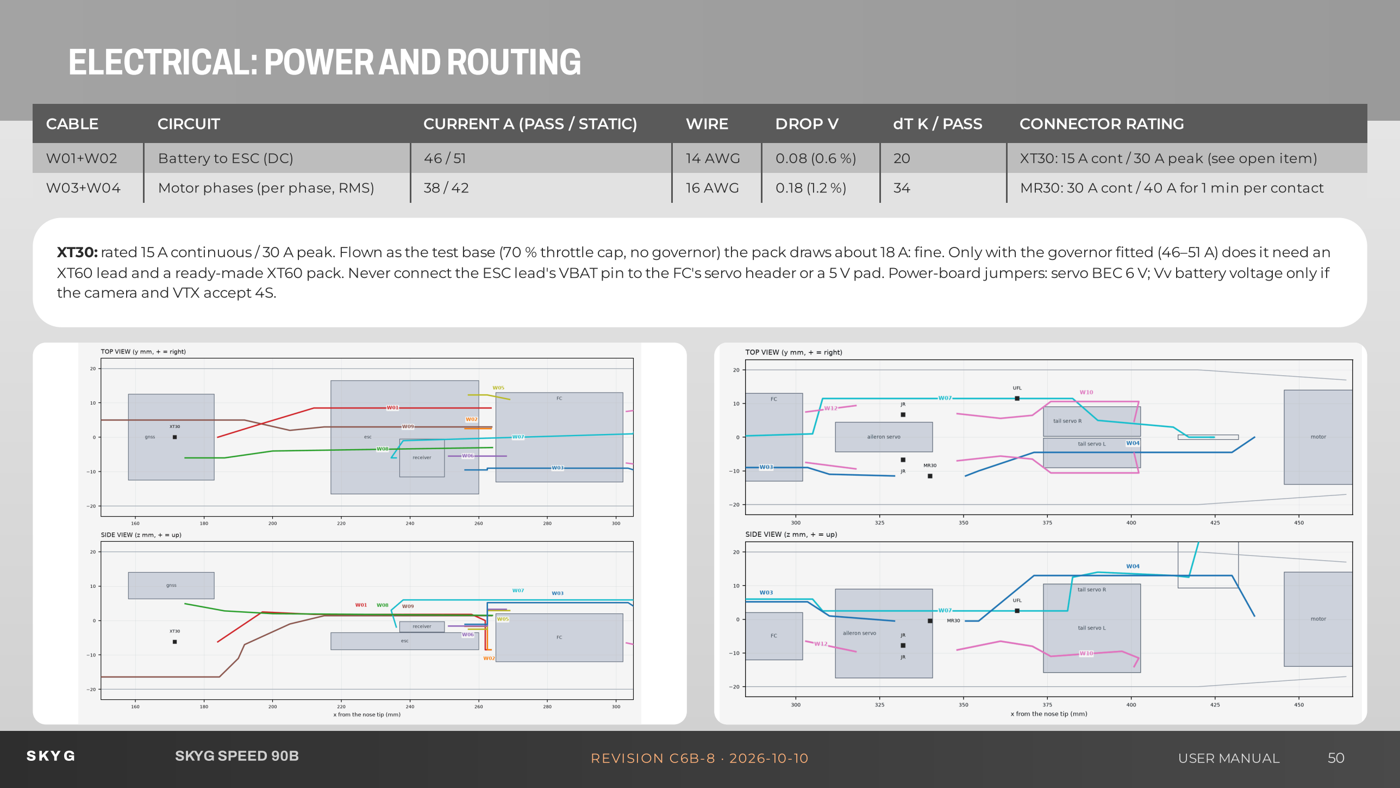
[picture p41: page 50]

CABLE | CIRCUIT | CURRENT A (PASS / STATIC) | WIRE | DROP V | dT K / PASS | CONNECTOR RATING
W01+W02 | Battery to ESC (DC) | 46 / 51 | 14 AWG | 0.08 (0.6 %) | 20 | XT30: 15 A cont / 30 A peak (see open item)
W03+W04 | Motor phases (per phase, RMS) | 38 / 42 | 16 AWG | 0.18 (1.2 %) | 34 | MR30: 30 A cont / 40 A for 1 min per contact

XT30: rated 15 A continuous / 30 A peak. Flown as the test base (70 % throttle cap, no governor) the pack draws about 18 A: fine. Only with the governor fitted (46–51 A) does it need an

XT60 lead and a ready-made XT60 pack. Never connect the ESC lead's VBAT pin to the FC's servo header or a 5 V pad. Power-board jumpers: servo BEC 6 V; Vv battery voltage only if

the camera and VTX accept 4S.

SKY G | SKYG SPEED 90B | REVISION C6B-8 · 2026-10-10 | USER MANUAL | 50

# ELECTRICAL:RECEIVERANTENNA

i

The receiver's antenna is a vertical dipole inside the fin, clear of

all metal: the RP1 V2 T-antenna's two 31 mm legs lie in a groove

on the fin's 30 % chord line with the T's joint (the feed) at the

centre. The antenna's own coax runs down a parallel groove

beside the lower leg into the tail module, to an in-line u.FL joint

just ahead of the tail joint; a 1.13 mm u.FL extension continues to

the receiver on the ESC. Unplug the u.FL joint with the MR30

and the servo plugs before pulling the tail module. Lay antenna

and coax in the grooves before the fin is glued; three dots of

epoxy, tape over the grooves.

SKY G | SKYG SPEED 90B | REVISION C6B-8 · 2026-10-10 | USER MANUAL | 51

# ARDUPILOTCONFIGURATION

Starting ArduPlane configuration for SkyG Speed 90B on the SpeedyBee F405 WING MINI (firmware

target SpeedyBeeF405WING, ArduPlane 4.5 or later). Load the .param file in Mission Planner (Config >

Full Parameter List > Load from file), then work through the bench checks.

Flight controller: on the wing-bay floor, arrow forward; servo BEC jumper set to 6 V for the ES9052MD

servos.

Firmware: ArduPlane 4.5 or later · Board: SpeedyBee F405 WING MINI (ArduPilot target:

SpeedyBeeF405WING)

The setup document and the starting .param file are in the package (ArduPilot folder). Verify every

value on the bench before flight.

## S KY G

# ARDUPILOTCONFIG

## SKYG SPEED 90B

### SPEEDYBEE F405 WING MINI

SKY G | SKYG SPEED 90B | REVISION C6B-8 · 2026-10-10 | USER MANUAL | 52

# FLIGHTTESTANDSPEEDSTAGES

i

The speed envelope opens in stages. Fly each stage only after the

ground checks and the previous stage pass: thrust-stand run, wing

load and twist test, control freeplay ≤ 0.2 mm (≤ 0.05 mm above 45

m/s), aileron hinge stiffness, and the tap test. At each run give short

aileron and pitch doublets; any buzz or vibration: throttle to zero,

gentle pull-up, land and inspect.

Full procedure, limits and log sheet: the test plan in the Engineering

folder.

Stage Vne | STAGE throttle limit | Expected level speed
30 m/s | 28 % | 24 m/s
35 m/s | 32 % | 28 m/s
40 m/s | 36 % | 32 m/s
45 m/s | 41 % | 37 m/s
50 m/s | 45 % | 41 m/s
55 m/s | 50 % | 45 m/s
60 m/s | 55 % | 50 m/s
65 m/s | 59 % | 53 m/s
70 m/s | 64 % | 58 m/s
75 m/s | 69 % | 62 m/s
80 m/s | 70 % (needs the governor) | 63 m/s
85 m/s | 70 % (needs the governor) | 63 m/s
90 m/s | 70 % (needs the governor) | 63 m/s
SKY G | SKYG SPEED 90B | REVISION C6B-8 · 2026-10-10 | USER MANUAL | 53

# S KYG

# SKYGSPEED90B

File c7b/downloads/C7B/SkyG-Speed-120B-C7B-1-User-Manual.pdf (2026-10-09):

S

K

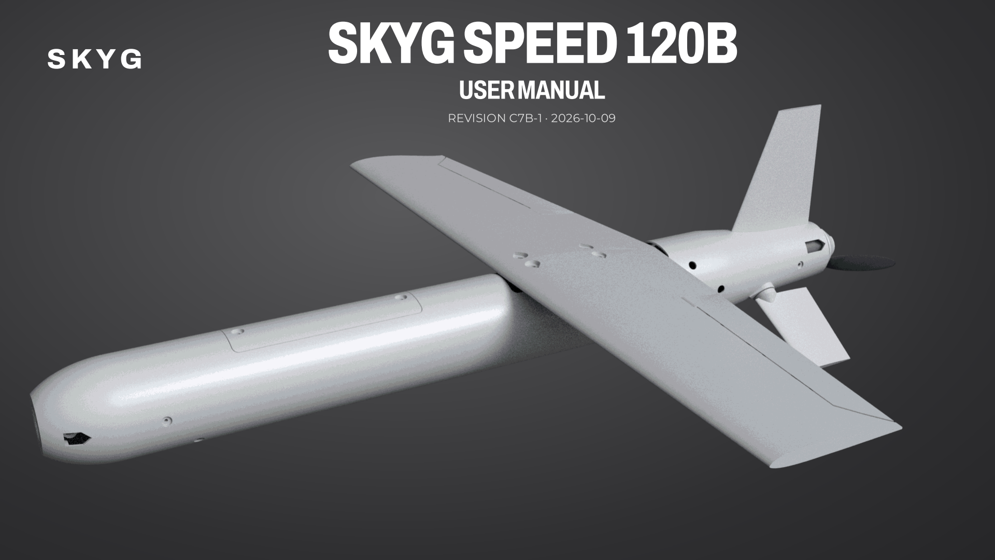
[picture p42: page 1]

Y

G

S

# KYG

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
VISIO
N

C
7

B

1 · 2

0

2

6

1

0

0

9

# PACKAGECONTENTS

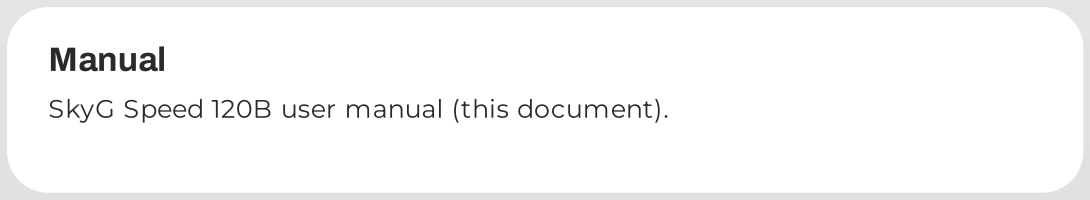
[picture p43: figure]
Manual

SkyG Speed 120B user manual (this document).

STL; pages in this manual).

Every printed part, in millimetres, ready for the slicer (print orientation:

Every printed part and the full assembly, for editing in any CAD program.

The wiring diagram as a separate large page.

Setup document and a starting .param file for the SpeedyBee F405 WING

Interactive 3D model (open the HTML file in a browser): every part exploded

Design record, parts list (BOM.csv), test plan and verification report.

SKY G | SKYG SPEED 120B | REVISION C7B-1 · 2026-10-09 | USER MANUAL | 2

# TABLEOFCONTENTS

### Introduction

General aircraft data | 05
Aerodynamic design | 06
Aerodynamic characteristics | 07
Performance and speed stages | 08
Compartment layout | 10
Camera nose variants | 11

### Recommended equipment

Recommended electronics | 13
Recommended accessories | 14
Powertrain | 15

### Print settings

Print settings | 17
Parts list | 19
Parts orientation | 20

### Assembly guide

Fuselage assembly | 31
Wing assembly | 32
Tail module | 35
Equipment and wiring | 41
Camera nose | 44
Final assembly | 46
Finishing build | 47
Wiring diagram | 48
Electrical integration | 49
ArduPilot configuration | 53
Flight test and speed stages | 54
SKY G | SKYG SPEED 120B | USER MANUAL | 3

# SKYGSPEED120B

SkyG Speed 120B is a compact, hand-launched speed aircraft: a 3D-

printed fuselage in three plug-together modules and a separate

camera nose, a 430 mm straight wing on a carbon spar, and an all-

moving canted tail driven by two micro servos. A single pusher motor

sits in the tail cone behind the tail.

The airframe is printed in foaming PLA Aero on a 0.4 mm nozzle; steel

and carbon parts carry the concentrated loads (spar, aileron hinge

pins and torque rods, tail shafts). Six interchangeable camera noses

take a micro FPV camera, a Raspberry Pi camera or a DJI O4 Air Unit,

each with an open or a clear-dome face.

It is built for straight-line speed: about 107 m/s finished with the

planned rpm governor, and about 78 m/s until that governor is fitted,

flown up through never-exceed stages.

SKY G | SKYG SPEED 120B | REVISION C7B-1 · 2026-10-09 | USER MANUAL | 4

# GENERALAIRCRAFTDATA

Wingspan | 430 mm
Wing area | 3.65 dm²
Length | 471 mm
Centre of gravity | 7 mm behind the wing leading edge at the root
All-up weight | 685 g (micro-camera nose)
Stall speed | 13.0 m/s
Top speed (model) | 106–107 m/s with the governor
Airfoil | MH45, ailerons 3° reflex
Root / tip chord | 100 / 70 mm
MAC | 86 mm
Aspect ratio | 5.1
Wing loading | 104 g/dm²

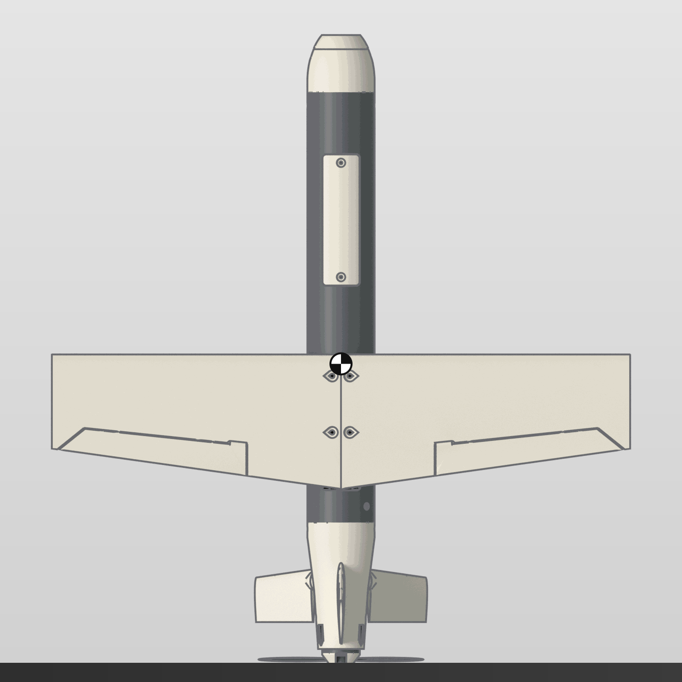
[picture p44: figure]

SKY G | SKYG SPEED 120B | REVISION C7B-1 · 2026-10-09 | USER MANUAL | 5

# AERODYNAMICDESIGN

The wing uses the MH45 section, a low-moment reflexed profile, with

both ailerons rigged 3° trailing edge up. The design CG is at 8 % of the

mean chord, 6.5 % static margin ahead of the neutral point (x 258 mm

from the nose datum): stable without a tail download penalty at speed.

Pitch and yaw come from two all-moving tail panels at 35° anhedral,

mixed like a V-tail, with a fixed fin on top. The Dutch roll is lightly

damped at low speed, so the flight controller's yaw damper is part of the

setup.

Flutter of the wing, ailerons and tail panels was analysed (strip theory

with the CAD-derived stiffness and masses): the lowest predicted

instability is 134 m/s, above 1.2 × the 90 m/s top stage. The test plan opens

the speed envelope in stages and measures the stiffness the margin

depends on.

SKY G | SKYG SPEED 120B | REVISION C7B-1 · 2026-10-09 | USER MANUAL | 6

# AERODYNAMICCHARACTERISTICS

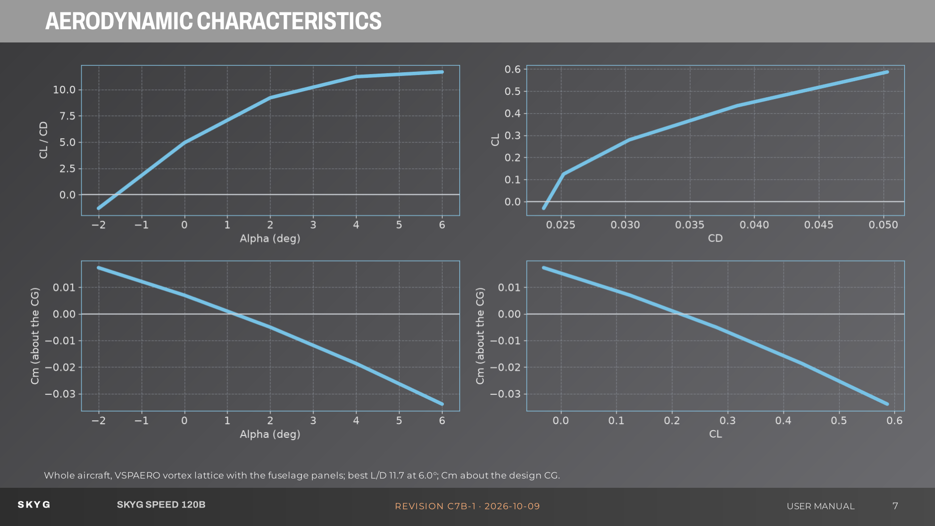
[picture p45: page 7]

Whole aircraft, VSPAERO vortex lattice with the fuselage panels; best L/D 11.7 at 6.0°; Cm about the design CG.

SKY G | SKYG SPEED 120B | REVISION C7B-1 · 2026-10-09 | USER MANUAL | 7

# PERFORMANCEANDSPEEDSTAGES

Motor | T-Motor F50 2207 2150KV
Propeller | Gemfan 5x7.5E Vortex
Battery | BetaFPV LAVA II 3S 680 95C LiHV
Static thrust | 1572 g at 65 A (thrust / weight 2.29)
Throttle cap (prop rpm rating) | 70 %

Top speed

78–78 m/s now; 106–107 m/s with the

governor

Full-throttle time

about 1.1 min on the four packs (bursts of ≤

10 s)

Stage Vne | STAGE throttle limit | Expected level speed
30 m/s | 23 % | 23 m/s
35 m/s | 26 % | 28 m/s
40 m/s | 29 % | 32 m/s
45 m/s | 33 % | 37 m/s
50 m/s | 36 % | 41 m/s
55 m/s | 40 % | 45 m/s
60 m/s | 44 % | 50 m/s
65 m/s | 47 % | 53 m/s
70 m/s | 51 % | 58 m/s
75 m/s | 55 % | 62 m/s
80 m/s | 59 % | 66 m/s
85 m/s | 63 % | 70 m/s
90 m/s | 67 % | 74 m/s

No airspeed sensor: each stage is held by a throttle limit on a transmitter switch (LAUNCH =

full cap for the throw and climb-out only, STAGE = the limit). Level runs only; speed from

GPS two-way passes.

SKY G | SKYG SPEED 120B | REVISION C7B-1 · 2026-10-09 | USER MANUAL | 8

# FILES

i

Every printed part is supplied as STL (for printing) and

STEP (for editing), plus the complete assembly as one

STEP file. Left and right wing halves, ailerons and tail

panels are separate files because they are mirror

images. The interactive viewer in the package shows

every part, purchased item and cable in place.

SKY G | SKYG SPEED 120B | REVISION C7B-1 · 2026-10-09 | USER MANUAL | 9

6S 1360 mAh as four 3S packs (two side-by-side pairs, one

behind the other) on the tray under the wing; they stay in

and are charged through the port under the hatch;

Flight controller stack with the ESC on top, receiver,

aileron servo; reached with the wing off

Two tail servos, pushrods, horns and the motor; plugs off at

Camera and VTX (or the DJI O4 unit) in the removable

SKY G | SKYG SPEED 120B | REVISION C7B-1 · 2026-10-09 | USER MANUAL | 10

# CAMERANOSEVARIANTS

Nose | Camera | Battery centre for balance
N0M | 19 mm micro FPV camera + 20 × 20 VTX | x 228 mm
N0P | Raspberry Pi Camera Module 3 (test option) | x 216 mm (at its stop + nose ballast)
N0MD | micro camera behind a 40 mm dome, nano VTX under the hatch | x 0 mm
N0PD | Pi camera behind a dome | x 0 mm
N0O | DJI O4 Air Unit (Lite), ducted | x 0 mm
N0OD | DJI O4 behind a dome | x 0 mm
SKY G | SKYG SPEED 120B | REVISION C7B-1 · 2026-10-09 | USER MANUAL | 11

# RECOMMENDEDEQUIPMENT

i

This section lists the electronics and parts needed to complete the

aircraft. The full list with order quantities, specifications and sources is

BOM.csv in the package.

SKY G | SKYG SPEED 120B | REVISION C7B-1 · 2026-10-09 | USER MANUAL | 12

# RECOMMENDEDELECTRONICS

COMPONENT | MODEL / SPECIFICATION
Motor | T-Motor F50 2207 2150KV
Propeller (fixed) | Gemfan 5x7.5E Vortex
ESC | HDZero Halo 4in1 70A ESC AM32
Flight controller | SpeedyBee F405 WING MINI
GPS + compass | TBS M10Q GPS GLONASS (QMC5883 compass), 13.5 g
Servos | 3 × Emax ES9052MD or ES9052MD HV (Promodelhobby, Turkey)
Flight battery | 4 × BetaFPV LAVA II 3S 680 95C LiHV (2-pack)
Receiver | RadioMaster RP1 V2
FPV camera | Micro 19 mm FPV camera, e.g. RunCam Phoenix 2 or Caddx Ratel 2
Video transmitter + antenna | 20x20 analog or digital VTX with U.FL antenna
DJI O4 Air Unit (Lite) | DJI O4 Air Unit
SKY G | SKYG SPEED 120B | REVISION C7B-1 · 2026-10-09 | USER MANUAL | 13

# RECOMMENDEDACCESSORIES

ITEM | QTY
XT30 connector pairs | 2
Carbon tube | 1
Music wire 2.0 mm | 2
Pushrods 1.2 mm with Z-bend | 4
Pushrod keepers for 1.2 mm wire | 4
Z-bend pliers, 1.1 mm drill, 1.2 mm drill (as a hand reamer), small flat file | 0
Steel countersunk screw M3 x 16 | 2
M3 hex nut | 4
M2 x 6 countersunk screws (joints) | 4
Kapton / thin clear tape | as needed
Adhesives | as needed
Velcro strap + hook/loop | 2
Heat shrink + silicone wire | as needed
Silver steel rod 2.5 mm | 2
Brass tube 3 mm | 2
MR30 connector pairs | 1
Servo extension leads 300 mm | 3
Motor screws M3 | 4
Steel countersunk screw M3 x 12 | 2
ITEM | QTY
Steel cup washer M3 (countersunk finishing washer) | 4
Steel cup washer M2 (countersunk finishing washer) | 2
M2 x 6 countersunk screws (motor plate) | 2
Servo strap / zip tie + foam tape | 1
Steel rod 1.5 mm | 2
Vent tape | 1
15T servo arms | 1
Dupont housings + crimps (1-pin, 4-pin) | 3
Carbon-fibre tube 50 x 48 mm | 320 mm
M2 x 6 countersunk screws (tube) | 8
Structural epoxy | ~3 g
Thin CA | ~1 g
M2 x 6 countersunk screws (hatch) | 2
XT30 series adapter (2 into 1) | 2
XT30 parallel adapter (2 into 1) | 1
Balance series adapter 2 x 3S to 6S | 2
6S parallel balance board | 1
Charge / arming port leads | 1
SKY G | SKYG SPEED 120B | REVISION C7B-1 · 2026-10-09 | USER MANUAL | 14

# POWERTRAIN

i

Motor and prop. T-Motor F50 2207 2150KV (6S-rated, 24 V; Ø27 x 29.5 mm incl. shaft, 28.56 g, 16 x 16 mm M3 with 4 mm thread depth, 5 mm shaft, M5 x 10.75 mm prop

thread, 50 mOhm, I0 1.6 A @10 V; 54.8 A / 1273 Wpeak): the SkyG Speed 60 motor, same mount. Prop: Gemfan Vortex 5x7.5E fixed electric prop (glass-fibre polyamide,

3.7 g, hub 13 x 6 mm, 6.35 mm bore with the 5 mm adapter ring; Robocombo stock). Gemfan publishes no rpm rating: each batch is spin-tested to 45,600 rpm (1.2 x the

38,000 rpm governor ceiling) behind a shield before flight. Pusher: the 5x7.5R, or the E mounted front face toward the motor with the motor reversed in the ESC;

throttle-capped (no governor on the F405).

Throttle cap. The Gemfan 5 × 7.5E stays at or below 38,000 rpm. On a full 6S pack the unloaded prop would exceed it at full throttle, so the flight controller caps the

throttle at 70 %. Never raise it, and inspect the blades after every thrust-stand run and flying day.

rpm governor (open item). A governor would hold the prop at 38,000 rpm and let it use that rpm in level flight. ArduPilot's governor script does not run on the F405

flight controller, so until an H7 flight controller (C7 uses the Matek H743-WLITE) is fitted the throttle cap above applies: about 78 m/s instead of 107 m/s.

Battery. Four BetaFPV LAVA II 3S 680 95C LiHV packs: each side-by-side pair in series (XT30 series adapter), the two pairs in parallel (XT30 parallel adapter), 6S 1360

mAh. They stay in the aircraft and are charged through the port under the hatch (XT30 + 6S balance plug; 6S LiPo mode, 4.20 V per cell, at most 1C, attended, on a non-

flammable surface). The port's XT30 is also the arming plug. Full throttle in bursts of ≤ 10 s, then ≥ 30 s at low throttle: the ESC lives on its thermal mass. Static thrust in

the model: 1572 g at 65 A; confirm on a thrust stand before the first flight.

SKY G | SKYG SPEED 120B | REVISION C7B-1 · 2026-10-09 | USER MANUAL | 15

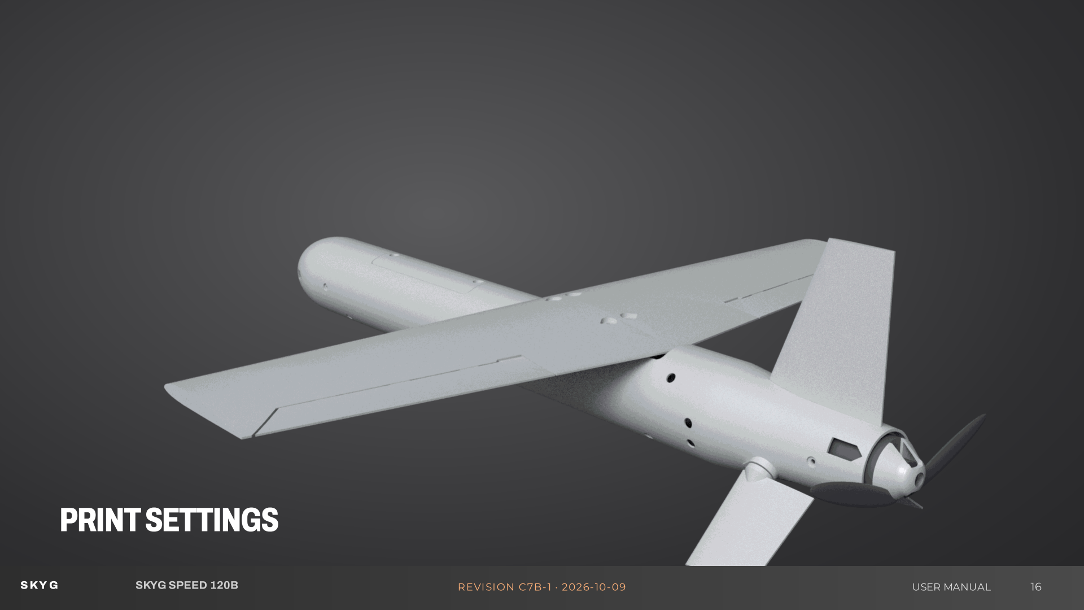
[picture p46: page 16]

# PRINTSETTINGS

SKY G | SKYG SPEED 120B | REVISION C7B-1 · 2026-10-09 | USER MANUAL | 16

# PRINTSETTINGS

i

Filament per part (no glass skin): PLA-CF wing halves (2 walls), PETG-CF ailerons, equipment tray, tail coupler, nut bars, hatch lips, duct inserts, motor plate and

spinner; PETG camera noses, hatch cover and GPS carrier (radio windows: never carbon-filled filament there); ASA tail module and fin (motor heat; the fin carries the

receiver antenna); PETG-CF tail panels and servo horns. 0.4 mm hardened-steel nozzle, 0.20 mm layers; every part fits both the H2S and the H2D build volume (340 ×

320 × 325 mm).

GENERAL GUIDELINES

- Fuselage, nose and hatch shells: 2 walls, 30 % lightning infill (it only grows under top surfaces: at 0 % the solid bosses and bridges print hollow and their tops collapse).
- Wing halves: PLA-CF, 2 walls, 8 % gyroid. Ailerons: PETG-CF, 1 wall, 5 % gyroid.
- Tail panels: 2 walls, 10 % gyroid. Fin: 2 walls, 15 %.
- Filament per part: see the parts list (PLA-CF, PETG-CF, PETG, ASA, PLA). CF filaments need a hardened-steel nozzle; ASA an enclosed printer.
- Tall standing parts: 5 mm brim, slow outer wall, enclosure door closed.

SUPPORTS: OFF

Every part is designed to print without supports in the orientation shown, and checked on the slicer's own G-code with these settings: nothing is printed over air and no bridge

is longer than 10 mm. Keep supports switched off and use the supplied .3mf files (they carry the settings). The downloads hold ONE set of Bambu Studio projects for the H2S

and the H2D: no G-code inside (G-code only fits the printer it was sliced for), tree supports on (auto). Open, select your printer, slice, print. Check the top of the aileron's torque-

rod bore on the first aileron.

SKY G | SKYG SPEED 120B | REVISION C7B-1 · 2026-10-09 | USER MANUAL | 17

# PRINTSETTINGS

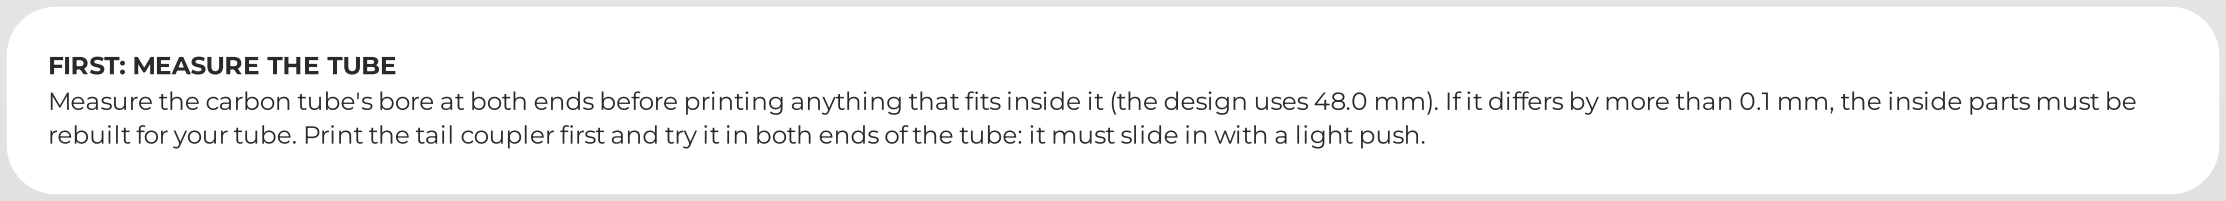
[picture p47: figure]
FIRST: MEASURE THE TUBE

Measure the carbon tube's bore at both ends before printing anything that fits inside it (the design uses 48.0 mm). If it differs by more than 0.1 mm, the inside parts must be

rebuilt for your tube. Print the tail coupler first and try it in both ends of the tube: it must slide in with a light push.

COUPON TESTS

Print the camera nose and try its spigot in the tube's front; slide the tail module onto the coupler; print the tray and slide it the whole length of the tube before cutting any

window. Print a 40 mm wing-root section in PLA-CF and check the spar fit.

SKY G | SKYG SPEED 120B | REVISION C7B-1 · 2026-10-09 | USER MANUAL | 18

# PARTSLIST

PART | MATERIAL | MASS
N0M NOSE (MICRO FPV) | PETG | 19.7 g
N0P NOSE (PI CAMERA) | PETG | 17.6 g
N0O NOSE (DJI O4) | PETG | 25.4 g
F3 TAIL MODULE | ASA | 15.4 g
HF FRONT HATCH | PETG | 4.2 g
FN FIN | ASA | 6.7 g
VTX SHELF (N0M) | PETG | 1.0 g
HG GPS CARRIER | PETG | 1.2 g
NB1 WING-NUT BAR FRONT | PETG-CF | 1.3 g
NB2 WING-NUT BAR REAR | PETG-CF | 1.2 g
HL1 HATCH LIP FRONT | PETG-CF | 0.9 g
HL2 HATCH LIP REAR | PETG-CF | 0.9 g
PART | MATERIAL | MASS
WR WING HALF RIGHT | PLA-CF | 47.2 g
WL WING HALF LEFT | PLA-CF | 47.3 g
AR AILERON RIGHT | PETG-CF | 4.0 g
AL AILERON LEFT | PETG-CF | 3.8 g
SR TAIL PANEL RIGHT | PETG-CF | 5.2 g
SL TAIL PANEL LEFT | PETG-CF | 5.2 g
M1 MOTOR PLATE | PETG-CF | 2.3 g
SP SPINNER | PETG-CF | 1.6 g
TR EQUIPMENT TRAY | PETG-CF | 24.1 g
TC TAIL COUPLER | PETG-CF | 10.4 g
CW COUNTERSUNK WASHER (PRINT 14) | PETG-CF | 0.1 g
WF WING-WINDOW FILLER | PETG-CF | 1.3 g

One aircraft with the N0M nose: 269 g printed. Only one camera nose is needed; the others

are options.

SKY G | SKYG SPEED 120B | REVISION C7B-1 · 2026-10-09 | USER MANUAL | 19

# PARTSORIENTATION

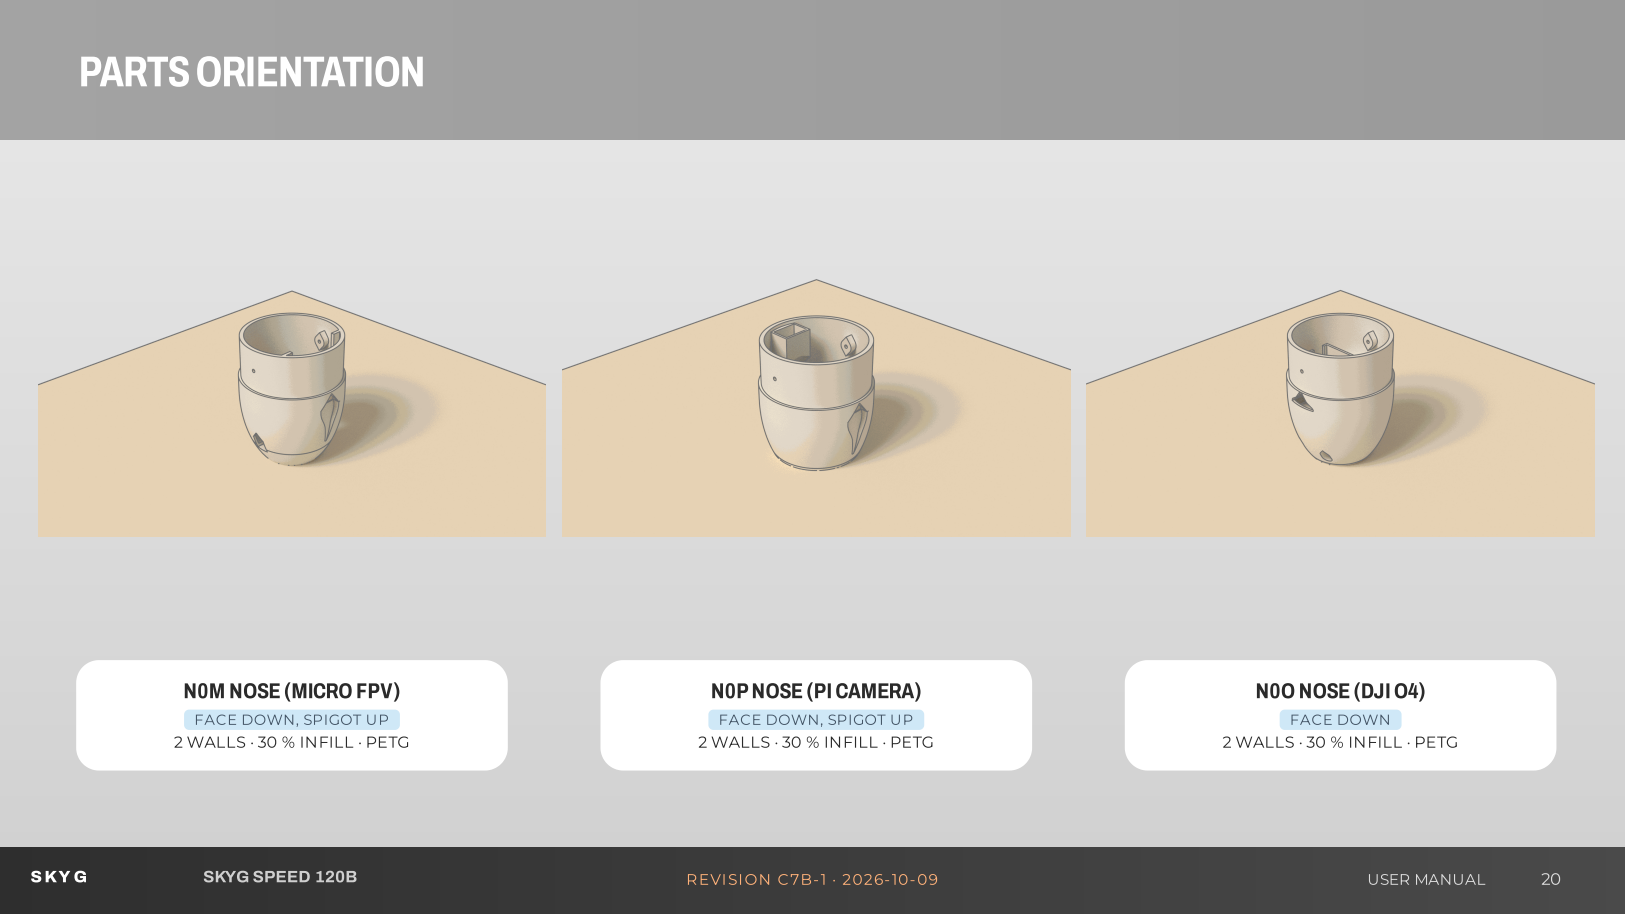
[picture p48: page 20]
N0PNOSE (PICAMERA); N0O NOSE (DJIO4); FACE DOWN; SKY G; SKYG SPEED 120B; REVISION C7B-1 · 2026-10-09; USER MANUAL

N0M NOSE (MICRO FPV)

FACE DOWN, SPIGOT UP

2 WALLS · 30 % INFILL · PETG

# PARTSORIENTATION

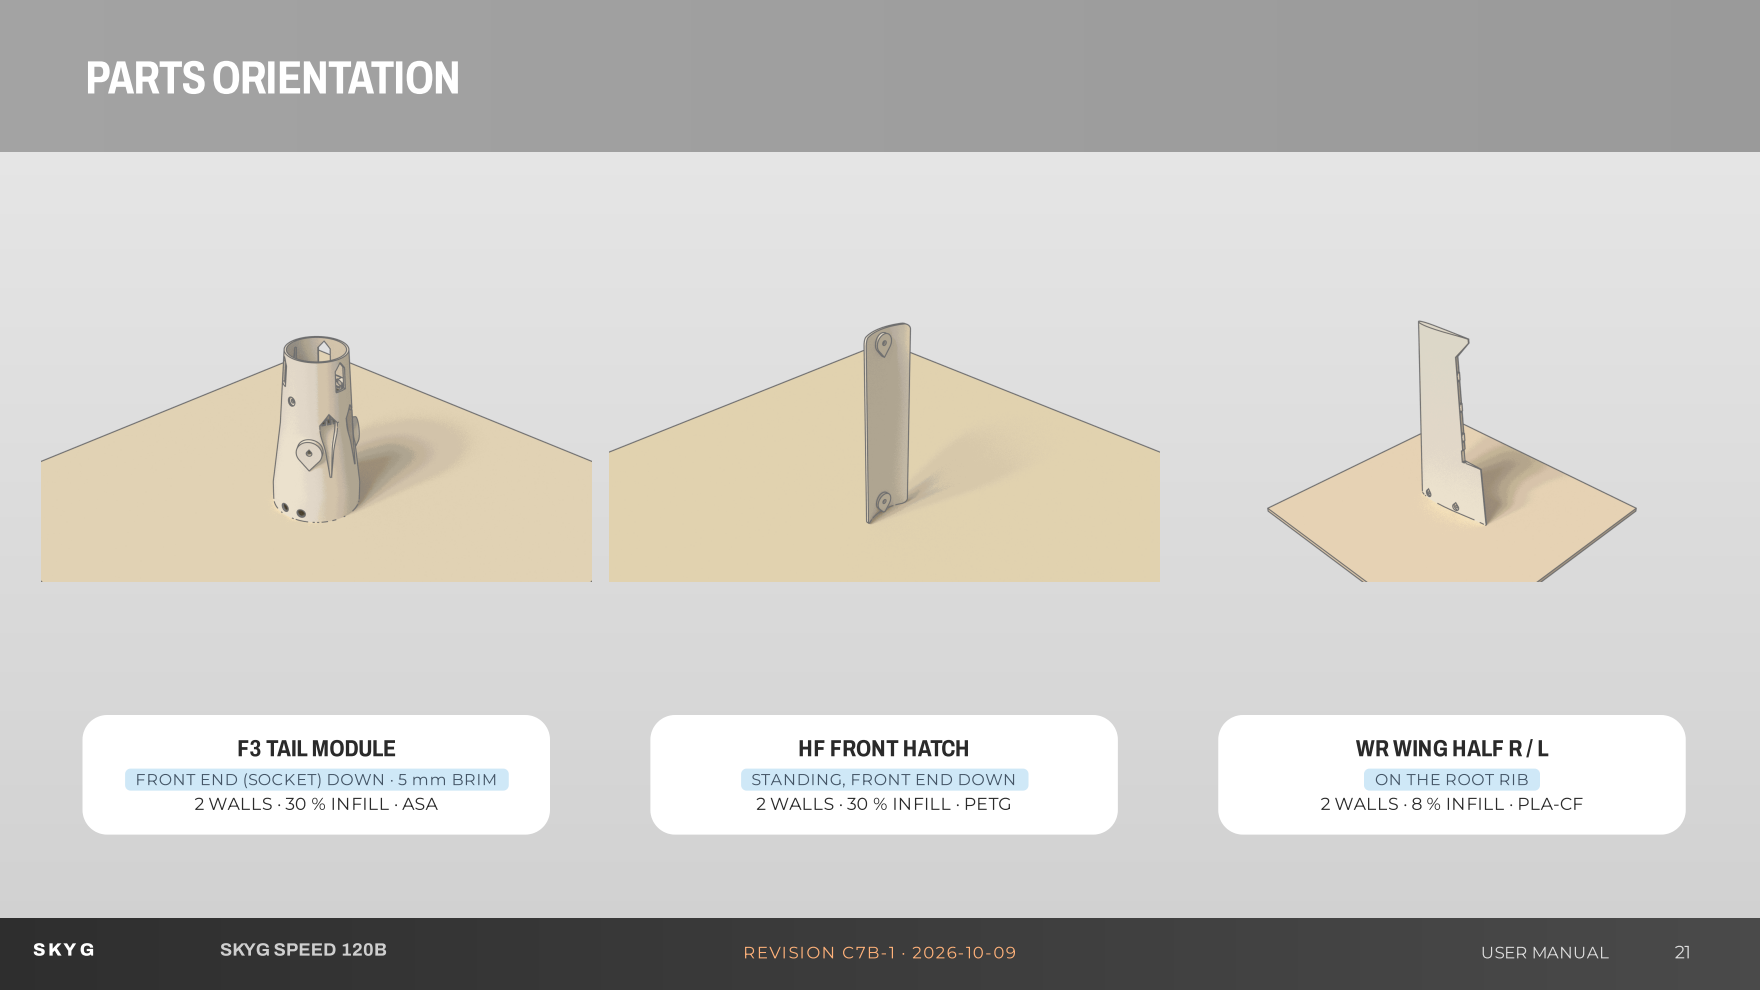
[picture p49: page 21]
F3 TAIL MODULE; SKY G; SKYG SPEED 120B; REVISION C7B-1 · 2026-10-09; USER MANUAL

HF FRONT HATCH

WR WING HALF R / L

FRONT END (SOCKET) DOWN · 5 mm BRIM

STANDING, FRONT END DOWN

ON THE ROOT RIB

2 WALLS · 30 % INFILL · ASA

2 WALLS · 30 % INFILL · PETG

2 WALLS · 8 % INFILL · PLA-CF

# PARTSORIENTATION

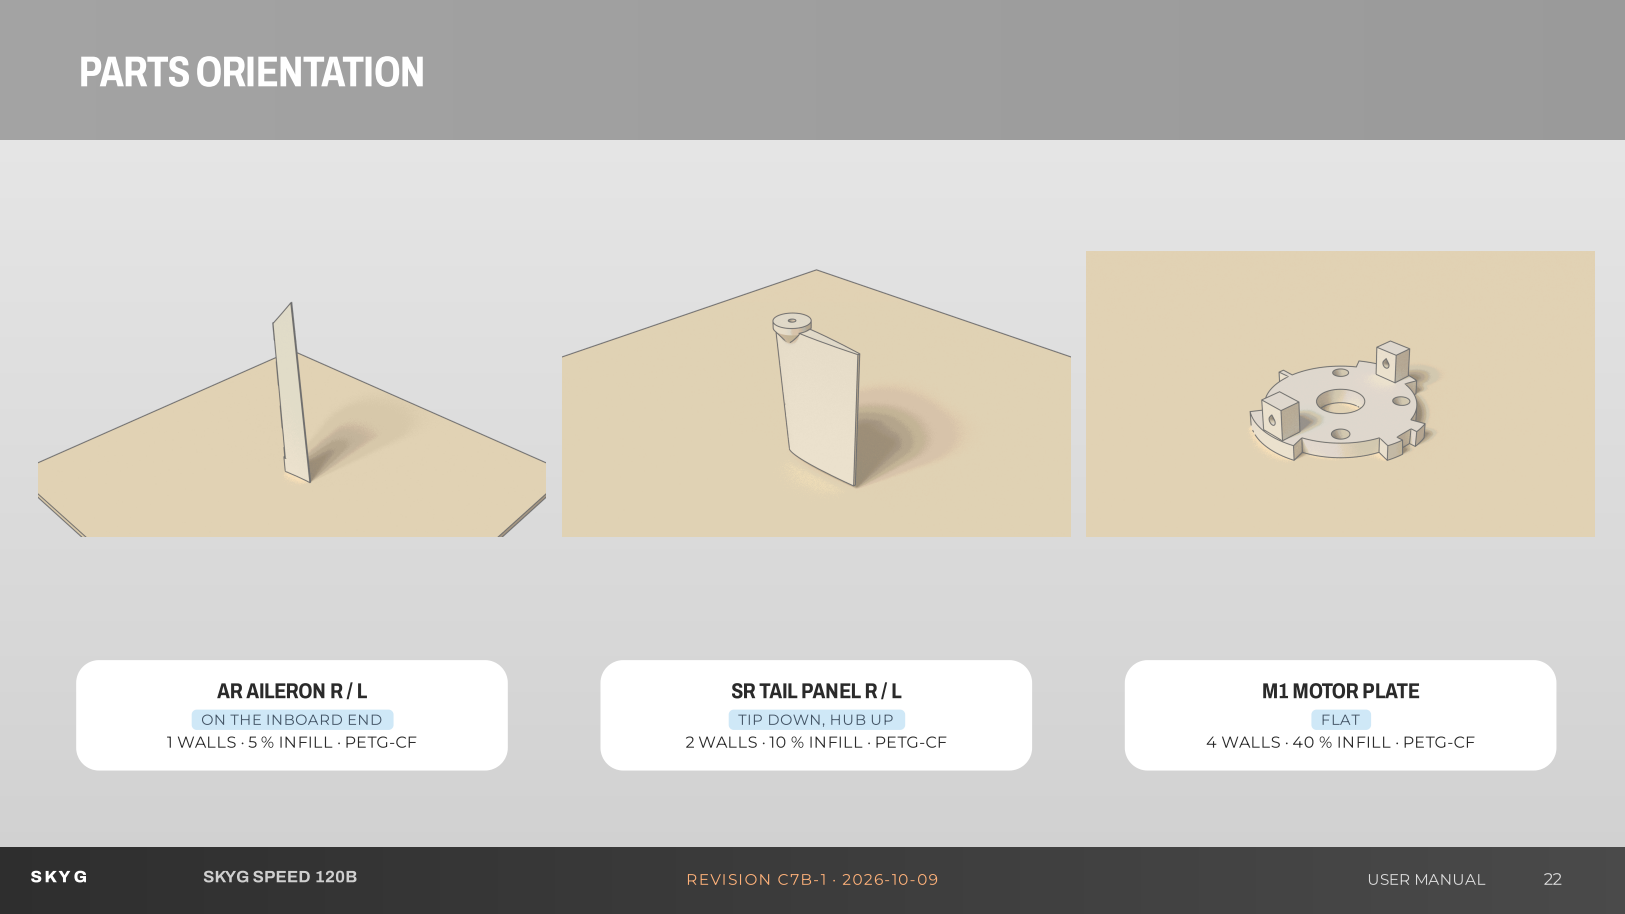
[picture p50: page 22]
AR AILERON R / L; M1 MOTOR PLATE; FLAT; SKY G; SKYG SPEED 120B; REVISION C7B-1 · 2026-10-09; USER MANUAL

SR TAIL PANEL R / L

ON THE INBOARD END

TIP DOWN, HUB UP

1 WALLS · 5 % INFILL · PETG-CF

2 WALLS · 10 % INFILL · PETG-CF

4 WALLS · 40 % INFILL · PETG-CF

# PARTSORIENTATION

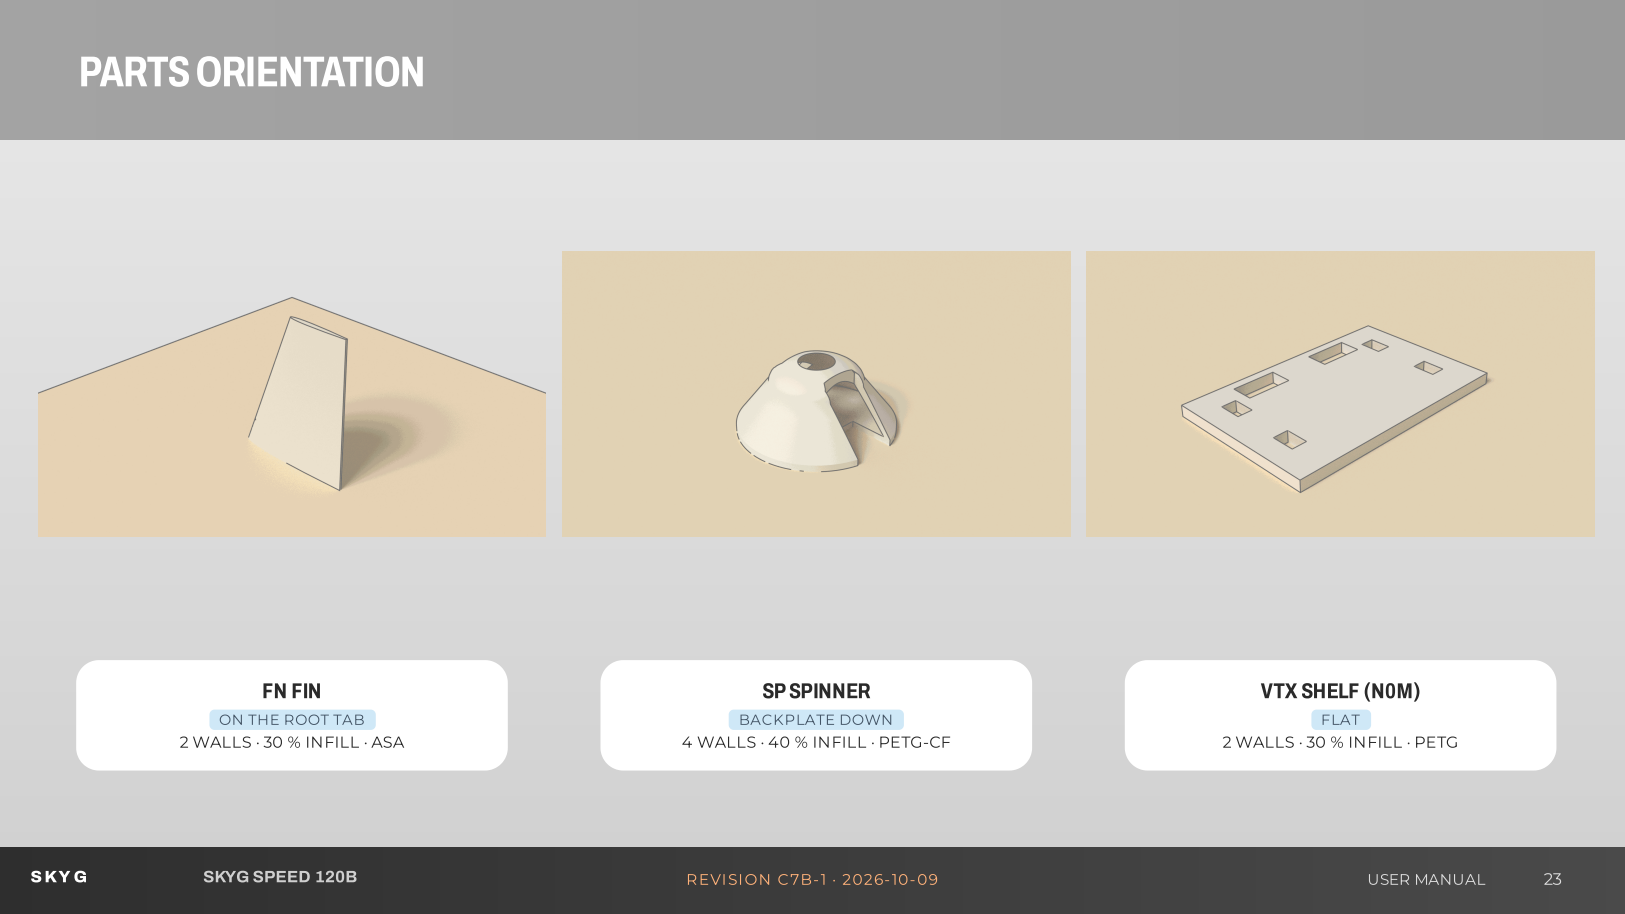
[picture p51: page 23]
FN FIN; SPSPINNER; BACKPLATE DOWN; VTX SHELF (N0M); FLAT; SKY G; SKYG SPEED 120B; REVISION C7B-1 · 2026-10-09; USER MANUAL

ON THE ROOT TAB

2 WALLS · 30 % INFILL · ASA

4 WALLS · 40 % INFILL · PETG-CF

2 WALLS · 30 % INFILL · PETG

# PARTSORIENTATION

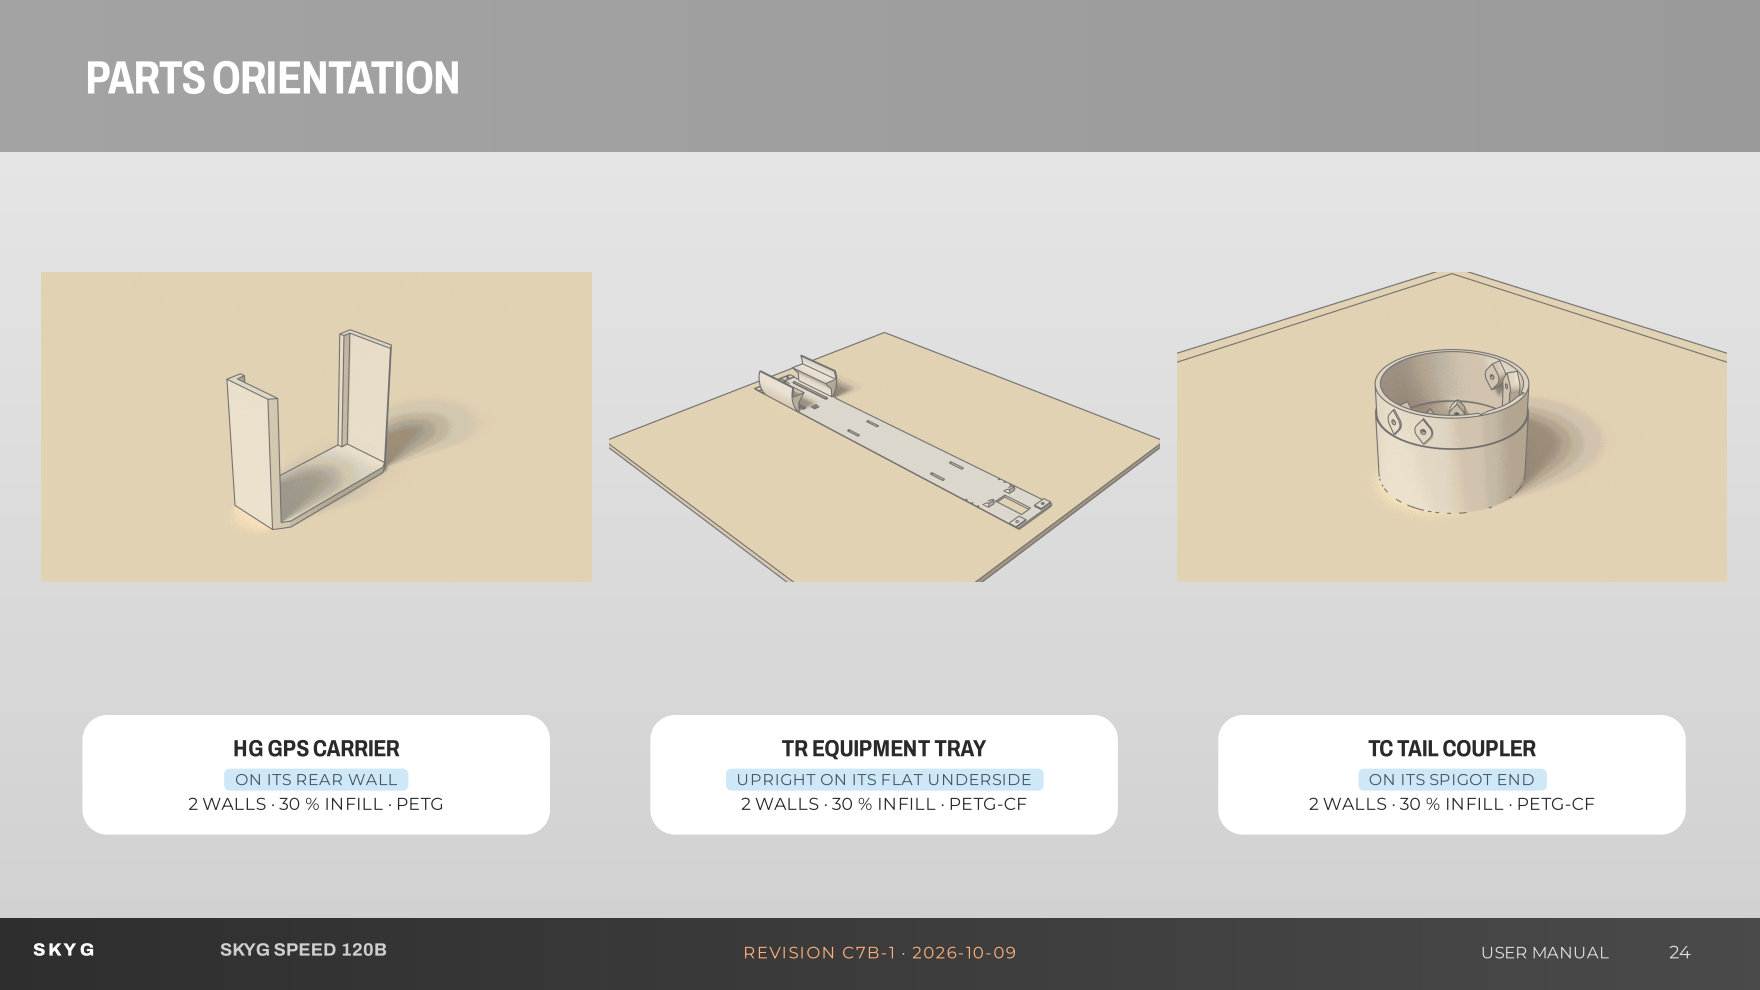
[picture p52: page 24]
HG GPSCARRIER; SKY G; SKYG SPEED 120B; REVISION C7B-1 · 2026-10-09; USER MANUAL

TR EQUIPMENT TRAY

TC TAIL COUPLER

ON ITS REAR WALL

UPRIGHT ON ITS FLAT UNDERSIDE

ON ITS SPIGOT END

2 WALLS · 30 % INFILL · PETG

2 WALLS · 30 % INFILL · PETG-CF

# PARTSORIENTATION

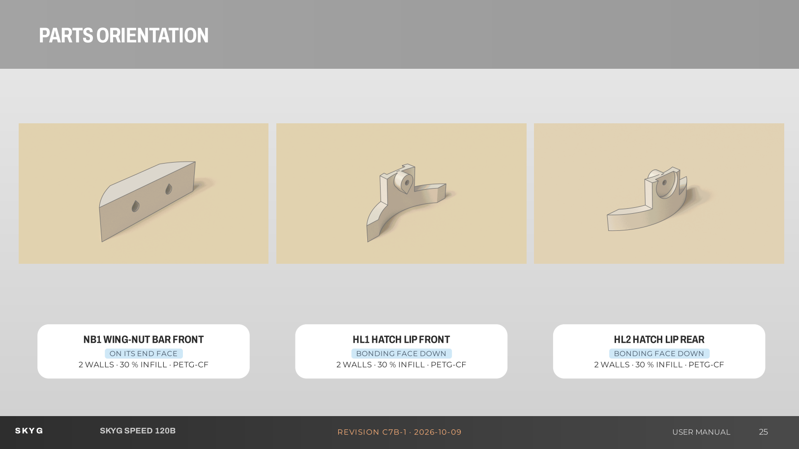
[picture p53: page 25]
HL1 HATCH LIPFRONT; HL2HATCH LIPREAR; SKY G; SKYG SPEED 120B; REVISION C7B-1 · 2026-10-09; USER MANUAL

NB1 WING-NUT BAR FRONT

ON ITS END FACE

BONDING FACE DOWN

2 WALLS · 30 % INFILL · PETG-CF

# PARTSORIENTATION

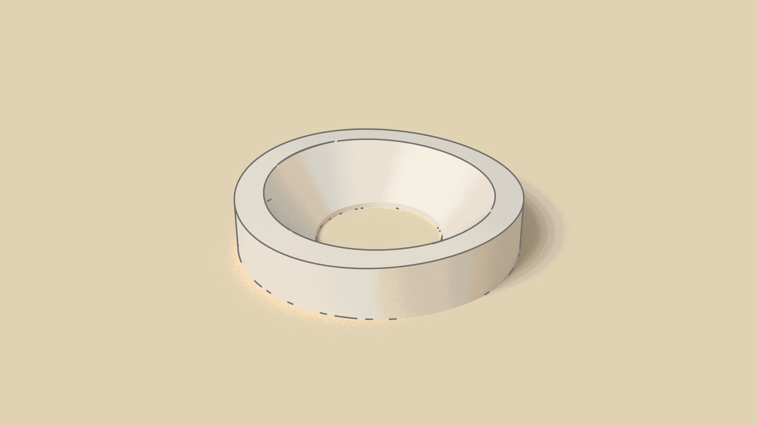
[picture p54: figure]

### CW COUNTERSUNKWASHER (PRINT 14)

FLAT FACE DOWN

2 WALLS · 30 % INFILL · PETG-CF

SKY G | SKYG SPEED 120B | REVISION C7B-1 · 2026-10-09 | USER MANUAL | 26

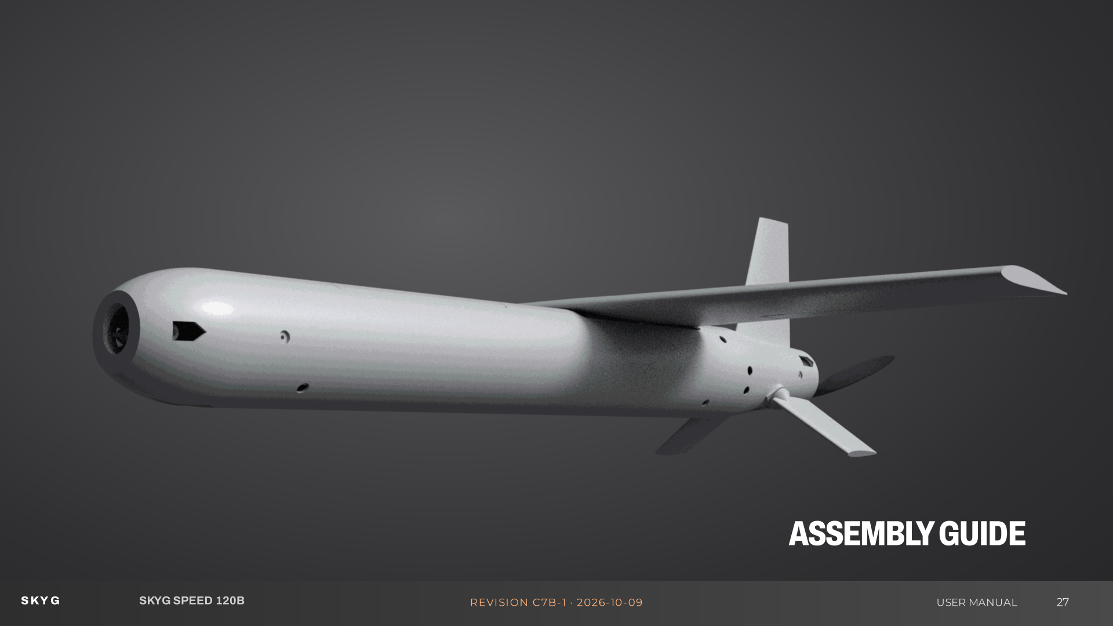
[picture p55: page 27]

# ASSEMBLYGUIDE

SKY G | SKYG SPEED 120B | REVISION C7B-1 · 2026-10-09 | USER MANUAL | 27

# CARBONTUBE

i

Cut the 50 × 48 mm carbon tube to 320 mm. Print


the 1:1 cutting template (two A4 pages, 100 % scale:

check its 100 mm bar), cut the strip out, wrap it

round the tube with its ends on the tube ends and

the TOP line along the top, tape it. Cut every

window inside the red lines with a diamond disc

and file to the line; drill the 2.2 mm holes. FFP3

mask, eye protection, vacuum at the disc or cut wet.

Seal every cut edge and hole with thin CA: carbon

conducts, a bare edge can cut a wire's insulation

and short it.

DIAMOND DISC

SKY G | SKYG SPEED 120B | REVISION C7B-1 · 2026-10-09 | USER MANUAL | 28

# CARBONTUBE

i

Scuff the bonding areas inside the tube (120 grit)

and clean them with alcohol. With structural epoxy

bond: the tail coupler TC into the aft end, its sleeve

over the whole ring behind the wing window, and

fix it with 2 × countersunk M2 × 6 in washers at the

sides (they hold it aligned while the epoxy cures

and back the bond up); the two wing-nut bars

NB1/NB2 across the wing-bay window (in through

the window, turned under its edges, pocket down);

the hatch lips HL1/HL2 under the front hatch

opening's ends (their screw bosses down, centred

under the opening). Let it cure before the tray goes

in.

EPOXY

SKY G | SKYG SPEED 120B | REVISION C7B-1 · 2026-10-09 | USER MANUAL | 29

# EQUIPMENTTRAY

i

Build the tray on the bench: the ESC under the FC

ledges, the FC stack, receiver, aileron servo, the four

packs and all wiring as on the next pages. Take the

camera nose off, push the tray into the tube from

the front until its screw holes line up, and fix it with

4 × countersunk M2 × 6 screws through the tube (do

not overtighten: they thread into printed pillars).

Every external screw (the tube, the tail joint, the

motor plate) sits flush in a printed countersunk

washer (CW) pressed into its 5 mm hole: print 14,

push one into each hole before the screw. To service

the equipment or inspect the packs: nose off,

unhook the aileron pushrods, unplug the tail-

module plugs, four screws out, slide the tray forward

(the packs come out with it).

COUNTERSUNK M2 × 6

SKY G | SKYG SPEED 120B | REVISION C7B-1 · 2026-10-09 | USER MANUAL | 30

# FUSELAGEASSEMBLY

i

The camera nose plugs into the tube's front (its

spigot is sized to the tube's bore) with 2 ×

countersunk M2 × 6, flush in their printed washers,

into its bosses; the tail module slides onto the tail

coupler's spigot (the four pads on the coupler slide

in the grooves inside the module) and is held by 4 ×

countersunk M2 × 6 (two each side: at the side and

NOSE((N0M)); CARBONTUBE++EQUIPMENTTRAY; F3 TAILMODULE; COUNTERSUNKM2x6 INWASHERS

25° below it), each in a printed washer in its 5 mm

hole, as on the tube. Nothing is glued: both

modules come off for service. They must slide on by

hand; if the bore is tight, sand the spigot, never

force it.

M2 × 6 SCREWS

SKY G | SKYG SPEED 120B | REVISION C7B-1 · 2026-10-09 | USER MANUAL | 31

# WINGASSEMBLY

i

WWIINNGGHHAALLFF RR; WWIINNGGHHAALLFF LL; 55xx33xx440000 mmmmCCAARRBBOONNTTUUBBEE; dihedral).; EPOXY; SKY G; SKYG SPEED 120B; REVISION C7B-1 · 2026-10-09; USER MANUAL

Cut one 400 mm length of 5 × 3 mm carbon tube

and slide it through both wing halves (200 mm into

each). Epoxy the tube in the bores and the two root

ribs together with the whole wing flat on a table (0°

# WINGASSEMBLY

i

Set each aileron in place: its rounded nose sits in

the cove along the wing's hinge face and the wing's

three knuckles enter the pockets in the nose. Push

a 132 mm length of 1.5 mm steel rod in from the

wingtip through the tip, the aileron and the

knuckles. Wick thin CA into the aileron's four glue

holes only, then plug the tip hole. The aileron must

swing freely.

THIN CA

SKY G | SKYG SPEED 120B | REVISION C7B-1 · 2026-10-09 | USER MANUAL | 33

# WINGASSEMBLY

i

22..00 MMMMTTOORRQQUUEERROODD

HORN+PIN

FLATTEDENDINTOTHEKNUCKLE(EPOXY)

Bend a 12 mm horn down at one end of each 2.0

mm rod with a 5.5 mm pin outboard at its tip, and

file a 0.3 mm flat on the last 9 mm of the straight

end, opposite the horn. Push it in from the root face

until the flat enters the D-bore of the aileron's root

knuckle; epoxy the end and hold the aileron 3°

trailing edge up while it cures.

EPOXY

SKY G | SKYG SPEED 120B | REVISION C7B-1 · 2026-10-09 | USER MANUAL | 34

# TAILMODULE

i

## TTAAIILLPPAANNEELLRR

## TTAAIILLPPAANNEELLLL

SHAFT+COLLARHORN

33//3322iinnBBRRAASSSSBBUUSSHHIINNGGSS

Press a 10 mm brass bushing into each side boss of

F3. Epoxy a 2.5 mm steel shaft 35 mm into each tail

panel's root bore. From the open front of F3, push

each shaft through its bushing and fit the wheel-

collar horn with its 8 mm brass plate standing along

the panel's normal (not pointing forward), 0.5 mm

end play, set screw on a filed flat.

EPOXY

SKY G | SKYG SPEED 120B | REVISION C7B-1 · 2026-10-09 | USER MANUAL | 35

# TAILMODULE

i

Screw the motor to the M1 plate on the bench with

its 4 × M3 (heads on the plate's front face). Slide the

plate into the rear of F3 until it sits on the seat ring,

its two side lugs in the ring's pockets and its edge

notches on the cooling windows, then fix it with 2 ×

countersunk M2 × 6 through the tail module's sides

M1MOTORPLATE; F50 22072150KV; SPINNER; PROP+M5 NUT; 2xM2x6 INWASHERS(SIDES)

into the lugs, each in a printed washer in its

counterbore, flush (no glue: the plate comes out for

a different motor). Fit the spinner backplate, the

prop (Gemfan Vortex 5x7.5E fixed electric prop

(glass-fibre polyamide, 3.7 g, hub 13 x 6 mm, 6.35

mm bore with the 5 mm adapter ring) and the thin

M5 nut.

M2 × 6 SCREWS

SKY G | SKYG SPEED 120B | REVISION C7B-1 · 2026-10-09 | USER MANUAL | 36

# TAILMODULE

## 1155TTAARRMM((HHOOLLEERREEAAMMEEDD11..22mmmm))

i

Stand both ES9052MD servos through the cut-outs

in the F3 floor on foam tape on the bottom skin, a

strap over them, output at the aft end, leads along

the side walls. One-sided 15T arm pointing

outboard; file a 0.3 mm flat on the inboard end of

each 2.5 mm stabilator shaft and epoxy the printed

horn (THR / THL) on it, arm along the panel's

normal. Drill the servo arm's 6.7 mm hole 1.1 mm

and ream it by hand with a 1.2 mm bit (and the

horn's hole the same): the wire must turn with no

play. 1.2 mm Z-bend pushrod: Z-bend in the arm,

90° L-bend at the horn end pushed outboard

through the horn's reamed hole, snap-on keeper on

the protruding end (unclip it to take the tail

module off). Free play at each panel trailing edge <=

0.2 mm. Check both panels move freely through

±20°.

SERVO TAPE

SKY G | SKYG SPEED 120B | REVISION C7B-1 · 2026-10-09 | USER MANUAL | 37

# TAILMODULE

i

FFNNFFIINN; SSLLOOTT((CCAA)); CA GLUE; SKY G; SKYG SPEED 120B; REVISION C7B-1 · 2026-10-09; USER MANUAL

Glue the fin into the top slot of F3 with CA, vertical

and square to the wing.

# FUSELAGEASSEMBLY

i

Bond the printed GPS carrier (HG) under the rear of

the PETG hatch cover (the GPS's radio window:

never paint it with metallic paint). Put foam tape on

the carrier's two side lips and slide the TBS M10Q

GPS in from the front, patch up, onto the lips

against the rear wall: it is carried from below, with

nothing but air and the cover between its patch

and the sky. The cover is held by two flush

countersunk M2 × 6 screws in steel cup washers, one

at each end, into the bosses under the bonded lips

(no magnets: suction and the GPS's weight would

lift them at speed). Leave a slack loop in the GPS

lead so the cover lifts off. With the cover off you

reach the charge / arming port (XT30 and 6S

balance plug), the FC's USB-C socket parked beside

them (setup, parameters, logs) and the FC itself.

FOAM TAPE

SKY G | SKYG SPEED 120B | REVISION C7B-1 · 2026-10-09 | USER MANUAL | 39

# FUSELAGEASSEMBLY

i

The four packs stay in the aircraft: on the bench, lay

them on the tray's rear floor as two side-by-side

pairs (on their sides), the front pair's leads out of its

rear end and the rear pair's out of its front end into

the 8 mm gap. Set the rear pair's rear edge at the

tick the balance table gives (ticks every 5 mm on

the floor edges), foam tape under each pack and

one strap round each pair through the slots. Plug

each pair into its XT30 series adapter and 2 x 3S

balance adapter (measure 6S, about 25 V full, and

the polarity), then both pairs into the parallel

adapter and balance board, only with the pairs

within 0.05 V per cell; tape the adapters as one

block on the rear pair. Lead the main XT30 and the

6S balance plug forward to the front pair, under the

hatch: that is the charge / arming port.

VELCRO STRAP

SKY G | SKYG SPEED 120B | REVISION C7B-1 · 2026-10-09 | USER MANUAL | 40

# EQUIPMENT

ESC((ONTHESTACK)); AILERONSERVO

SPEEDYBEEF405 WINGMINI RP1RECEIVER

## TT--AANNTTEENNNNAA

i

Front bay of the tray: slide the HDZero Halo ESC in

from behind under the two FC ledges, onto its rails

(foam tape), motor on M1. SpeedyBee F405 WING

MINI stack on the ledges above it on foam tape and

a strap, arrow forward, servo BEC jumper at 6 V; the

RP1 V2 receiver on edge on the right ledge (foam

tape), its T-antenna straightened into the fin's

dipole. Aileron servo through the tray's floor at the

rear, output aft.

FOAM TAPE

SKY G | SKYG SPEED 120B | REVISION C7B-1 · 2026-10-09 | USER MANUAL | 41

# EQUIPMENT

i

ES9052MD aileron servo standing through the

wing-bay floor on foam tape; two-sided 15T arm.

Each torque rod has one 90° bend (the horn leg, 6

mm from the centreline); epoxy the printed horn

(AHR / AHL) on the leg, 4 mm deep. Drill the arm's

4.3 mm holes 1.1 mm and ream them by hand with

a 1.2 mm bit (and both horns' holes): the wire must

turn with no play. Each horn connects to the arm

with a 1.2 mm Z-bend pushrod: Z-bend in the arm,

90° L-bend pushed inboard through the horn's

reamed hole, snap-on keeper on the protruding

end. Check: with the servo powered, each aileron

trailing edge moves <= 0.2 mm (free play lowers

aileron flutter to about 33 m/s). Set both ailerons 3°

trailing edge up at servo neutral. No play at either

end.

Z-BENDS

SKY G | SKYG SPEED 120B | REVISION C7B-1 · 2026-10-09 | USER MANUAL | 42

# EQUIPMENT

i

Behind the FC: the battery lead from the port's XT30

down to the power board's BAT pads; the 14 AWG

ESC feed from its ESC pads down onto the ESC's

rear; ESC signal (M1, GND, TLM) up to S1; GPS and

USB leads on the left. Motor phases from the ESC's

rear down behind it and along the lower left wall

past the packs to the MR30 beside the aileron servo;

the left tail servo lead along the left wall below

them; the right tail servo and aileron leads along

the right wall (the aileron lead under the tray floor,

up through the hole behind the ESC); the ELRS

coax along the right side of the packs to the u.FL

joint and into the fin. Cut lengths and lanes:

Electrical Integration manual. Unplug the MR30,

the u.FL joint and the servo plugs before pulling the

tail module.

HEAT SHRINK

SKY G | SKYG SPEED 120B | REVISION C7B-1 · 2026-10-09 | USER MANUAL | 43

# CAMERANOSE

i

Slide the 19 mm camera in from the open rear until

the lens reaches the face; 2 × M2 × 8 pan head + 2 ×

M2 washer (5 mm OD) through the side seats, lens

flush, tilt 0–10° up. Fix the VTX to the printed VTX

shelf (foam tape + zip tie through its slots), slide the

shelf in from the rear onto its two rails and glue it;

video antenna in the two clips on the right wall.

Plug the one lead at the nose joint. Dome noses:

glue the printed dome ring 3 mm into the front of

the tube, then fit the clear dome over its lip with

canopy glue (no CA).

FOAM TAPE

SKY G | SKYG SPEED 120B | REVISION C7B-1 · 2026-10-09 | USER MANUAL | 44

# CAMERANOSE

i

DDJJIIOO44CCAAMMEERRAA((IINNIITTSSMMOOUUNNTT)); OO44MMOODDUULLEE((IINNTTOOTTHHEEDDUUCCTT)); 44xxMM22xx55; AANNTTEENNNNAASSLLOOTT; M2 × 5 SCREWS; SKY G; SKYG SPEED 120B; REVISION C7B-1 · 2026-10-09; USER MANUAL

DJI O4 option: clamp the camera in its mount with

4 × M2 × 5 through the side slots (at most 3.1 mm

into the mount). Plug the coax and 3-in-1 lead into

the module and slide it edge-first into the duct

until it stops; foam strip in the top groove, tape over

the rear edge, never over its faces.

# FINALASSEMBLY

i

Glue the printed window filler (WF) under the wing

root (epoxy), centred, with the wing on the tube so it

lines up with the window. Push an M3 nut up into

each of the bonded nut bars' pockets (two per bar).

Set the wing into the tube's rectangular window

(the filler plugs in) and bolt it with the steel

countersunk screws in steel cup washers (flush in

the recesses), two at each station, one in each wing

half (each half is clamped on its own, off the glued

seam): M3 × 16 at the front, M3 × 12 at the rear; they

pull the nut bars up against the tube from inside.

Snug them with a small driver, do not overtighten

(the nut bars are printed).

STEEL SCREWS

SKY G | SKYG SPEED 120B | REVISION C7B-1 · 2026-10-09 | USER MANUAL | 46

# FINISHINGBUILD

i

Before the first flight: every control surface moves the right way (pitch up: both

panel trailing edges up; right roll: right aileron up), throws ±10° on the tail panels,

about ±10° (±3.5 mm at the trailing edge) on the ailerons, 30 % expo; the prop turns

the right way and pushes aft; failsafe set to motor off.

Balance: CG 7 mm behind the wing leading edge at the root (mark it on the wing

underside). Set the packs at the balance tick; for the first flight 2 mm further

forward. If a heavy camera needs it, use the nose ballast cup.

SKY G | SKYG SPEED 120B | REVISION C7B-1 · 2026-10-09 | USER MANUAL | 47

# WIRINGDIAGRAM

S1 ·THROTTLE(MOTORESC)

SS33 ··AAIILLEERROONN

S4·V-TAILLEFT | S5 ·V-TAILRIGHT

FC

## RX (UART1)

GPS(UART3)

66SS((44××33SS,, 22SS22PP))

## MOTOR

i

The diagram shows the flight-controller outputs and where each device sits.

Signal, power and video leads follow the routes on the wiring page of the

assembly guide; the package has this diagram as a separate large page.

PAD | FUNCTION | DEVICE
S1 | Throttle (motor ESC) | ESC (DShot300, bidirectional)
S2 | Unused | Leave empty (DShot group with S1)
S3 | Aileron | Aileron servo (ES9052MD, wing bay)
S4 | V-tail left | Left tail-panel servo (ES9052MD, tail module)
S5 | V-tail right | Right tail-panel servo (ES9052MD, tail module)
SKY G | SKYG SPEED 120B | REVISION C7B-1 · 2026-10-09 | USER MANUAL | 48

# ELECTRICAL INTEGRATION

Battery → FC power board (80 A current sensor) → ESC (motor on M1) → MR30 at the tail joint → motor. Main DC path 14 AWG (59 A on a pass, 65 A static), motor phases 16 AWG (48 A

RMS). Cable lengths are measured on the 3D harness model; the cut list adds the termination allowances and slack. Full detail, pinouts, settings and tests: the Electrical Integration

manual (PDF in the package and on the web page).

ID | CABLE | FROM | TO | AWG | CUT mm
W00 | Pack leads and adapters | Each pack's own XT30 lead and 3S balance lead (front… | Adapter block on the rear pair: 2 x XT30 series adapters… | 18 | stock
W01a | Main battery lead | Parallel adapter output (XT30 male) | Charge / arming port: XT30 female, parked on the front… | 14 | 110
W01b | 6S balance lead | 6S parallel balance board output | Charge port: 7-pin JST-XH, parked beside the XT30 | 26 | 110
W01 | Battery lead (ESC side of the port) | XT30 male: plugs into the port to fly (the charger's… | FC power board BAT+ / BAT- pads | 14 | 40
W02 | ESC feed | FC power board ESC+ / ESC- pads | HDZero Halo 4in1 70A ESC AM32 BAT+ / BAT- pads (XT60… | 14 | 35
W03 | Motor phases, ESC side | HDZero Halo 4in1 70A ESC AM32 M1 pads (A, B, C) | MR30 female (ESC side), low on the left ahead of the… | 16 | 250
W04 | Motor phases, motor side | MR30 male | Motor phase wires (cut to 20 mm, butt-soldered + heat… | 16 | 140
W05 | ESC signal | HDZero Halo 4in1 70A ESC AM32 8-pin SH1.0 lead (only M1,… | FC S1 header (signal, GND); TLM to the R4 pad | 28 | 45
W06 | Receiver lead | RadioMaster RP1 V2 pads (5V, GND, TX, RX), on edge on… | FC receiver header (5V, GND, RX1, TX1) | 28 | 25
W07 | ELRS antenna coax | RP1 V2 u.FL | Dipole feed at the centre of the fin dipole (z 39.5) | coax | 385
W08 | GPS lead | TBS M10Q (VCC, GND, TX, RX, SDA, SCL) | FC GPS interface with compass (4V5, GND, RX3, TX3, SDA,… | 28 | 65
W09 | Video trunk (N0M nose) | Nose joint plug (camera on the nose; VTX on the nose or,… | FC pads: Vv, G, C1 (camera in), VTX (video out) | 28 | 90
W10 | Tail servo leads (L, R) | Emax ES9052MD in F3 (its stock lead) | JR plug pair lying flat beside the aileron servo | 26 | stock
SKY G | SKYG SPEED 120B | REVISION C7B-1 · 2026-10-09 | USER MANUAL | 49

# ELECTRICAL INTEGRATION(CONTINUED)

ID | CABLE | FROM | TO | AWG | CUT mm
W12 | Tail servo extensions (L, R) | JR plug pair (beside the aileron servo) | FC S4 (left) / S5 (right) | 26 | stock
W11 | Aileron servo lead | Emax ES9052MD lead (stock), aileron servo in the wing bay | FC S3 header | 26 | stock
W13 | USB-C extension | FC USB-C port | USB-C female socket, parked between the charge plugs… | coax | stock
SKY G | SKYG SPEED 120B | REVISION C7B-1 · 2026-10-09 | USER MANUAL | 50

# ELECTRICAL:POWERANDROUTING


CABLE | CIRCUIT | CURRENT A (PASS / STATIC) | WIRE | DROP V | dT K / PASS | CONNECTOR RATING
W01+W02 | Battery to ESC (DC) | 59 / 65 | 14 AWG | 0.10 (0.5 %) | 33 | XT30: 15 A cont / 30 A peak (see open item)
W03+W04 | Motor phases (per phase, RMS) | 48 / 53 | 16 AWG | 0.39 (1.8 %) | 55 | MR30: 30 A cont / 40 A for 1 min per contact

XT30: rated 15 A continuous / 30 A peak. Flown as the test base (70 % throttle cap, no governor) the pack draws about 22 A: fine. Only with the governor fitted (59–65 A) does it need an

XT60 lead and a ready-made XT60 pack. Never connect the ESC lead's VBAT pin to the FC's servo header or a 5 V pad. Power-board jumpers: servo BEC 6 V; Vv battery voltage only if

the camera and VTX accept 6S.

SKY G | SKYG SPEED 120B | REVISION C7B-1 · 2026-10-09 | USER MANUAL | 51

# ELECTRICAL:RECEIVERANTENNA

i

The receiver's antenna is a vertical dipole inside the fin, clear of

all metal: the RP1 V2 T-antenna's two 31 mm legs lie in a groove

on the fin's 30 % chord line with the T's joint (the feed) at the

centre. The antenna's own coax runs down a parallel groove

beside the lower leg into the tail module, to an in-line u.FL joint

just ahead of the tail joint; a 1.13 mm u.FL extension continues to

the receiver on the ESC. Unplug the u.FL joint with the MR30

and the servo plugs before pulling the tail module. Lay antenna

and coax in the grooves before the fin is glued; three dots of

epoxy, tape over the grooves.

SKY G | SKYG SPEED 120B | REVISION C7B-1 · 2026-10-09 | USER MANUAL | 52

# ARDUPILOTCONFIGURATION

Starting ArduPlane configuration for SkyG Speed 120B on the SpeedyBee F405 WING MINI (firmware

target SpeedyBeeF405WING, ArduPlane 4.5 or later). Load the .param file in Mission Planner (Config >

Full Parameter List > Load from file), then work through the bench checks.

Flight controller: on the wing-bay floor, arrow forward; servo BEC jumper set to 6 V for the ES9052MD

servos.

Firmware: ArduPlane 4.5 or later · Board: SpeedyBee F405 WING MINI (ArduPilot target:

SpeedyBeeF405WING)

The setup document and the starting .param file are in the package (ArduPilot folder). Verify every

value on the bench before flight.

## S KY G

# ARDUPILOTCONFIG

## SKYG SPEED 120B

### SPEEDYBEE F405 WING MINI

SKY G | SKYG SPEED 120B | REVISION C7B-1 · 2026-10-09 | USER MANUAL | 53

# FLIGHTTESTANDSPEEDSTAGES

i

The speed envelope opens in stages. Fly each stage only after the

ground checks and the previous stage pass: thrust-stand run, wing

load and twist test, control freeplay ≤ 0.2 mm (≤ 0.05 mm above 45

m/s), aileron hinge stiffness, and the tap test. At each run give short

aileron and pitch doublets; any buzz or vibration: throttle to zero,

gentle pull-up, land and inspect.

Full procedure, limits and log sheet: the test plan in the Engineering

folder.

Stage Vne | STAGE throttle limit | Expected level speed
30 m/s | 23 % | 23 m/s
35 m/s | 26 % | 28 m/s
40 m/s | 29 % | 32 m/s
45 m/s | 33 % | 37 m/s
50 m/s | 36 % | 41 m/s
55 m/s | 40 % | 45 m/s
60 m/s | 44 % | 50 m/s
65 m/s | 47 % | 53 m/s
70 m/s | 51 % | 58 m/s
75 m/s | 55 % | 62 m/s
80 m/s | 59 % | 66 m/s
85 m/s | 63 % | 70 m/s
90 m/s | 67 % | 74 m/s
SKY G | SKYG SPEED 120B | REVISION C7B-1 · 2026-10-09 | USER MANUAL | 54

# S KYG

# SKYGSPEED120B

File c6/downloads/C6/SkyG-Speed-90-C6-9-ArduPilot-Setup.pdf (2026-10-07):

# S KYG

# ARDUPILOTCONFIG

# SKYGSPEED90

SpeedyBee F405 WING MINI (ArduPilot target: SpeedyBeeF405WING) · ArduPlane 4.5 or later

REVISION C6-9 · 2026-10-07

# OVERVIEW


Starting ArduPlane configuration for SkyG Speed 90 on the SpeedyBee F405 WING MINI (firmware target SpeedyBeeF405WING, ArduPlane 4.5 or later). Load the .param

file in Mission Planner (Config > Full Parameter List > Load from file), then work through the bench checks.

Flight controller: on the wing-bay floor, arrow forward; servo BEC jumper set to 6 V for the ES9052MD servos.

WARNINGS

These are starting values, not a tested setup. Verify every output, direction and endpoint on the bench before the first flight.

Never raise THR_MAX: it protects the prop's rpm rating.

No airspeed sensor: the throttle limits do not stop a dive from building speed. Fly stage runs level.

SkyG Speed 90 was designed around an rpm governor at 29,500 rpm. ArduPilot cannot run the governor script on an F405 board. Until a governor is fitted (H7 flight controller

or a governed ESC), THR_MAX stays at 70 % and the stages that need more throttle are not flown (see the stage table).

SKYG SPEED 90 · REVISION C6-9 · 2026-10-07 · 2

# FRAME,ORIENTATIONANDLOGGING

PARAMETER; VALUE; NOTE; LOG_BACKEND_TYPE; Logs to the microSD card.; LOG_DISARMED; No logging while disarmed.

Board mounted on the wing-bay floor, arrow forward, components up (build guide). Log to the microSD card.

AHRS_ORIENTATION | 0 | FC arrow forward, upright. Change only if the board is mounted otherwise.

# OUTPUTS

S1 drives the motor with bidirectional DShot (rpm telemetry for the prop-rpm check). S1 and S2 form one timer group: S2 stays unused. S3 drives the single aileron servo (both

ailerons through the torque rods). S4 and S5 drive the left and right tail panels as a V-tail mix.

Servo endpoints are calculated for the Emax ES9052MD (about 11.1 us per degree) and the linkages: aileron 2.79:1 (12 mm horn, 4.3 mm arm hole), tail 1.19:1 (8 mm horn, 6.7 mm

arm hole). They are starting points: set the final values by measuring the deflections on the bench.

PARAMETER | VALUE | NOTE
SERVO1_FUNCTION | 70 | S1: throttle (motor ESC).
SERVO2_FUNCTION | 0 | S2: unused (shares the DShot timer group with S1).
SERVO3_FUNCTION | 4 | S3: aileron (one servo drives both ailerons).
SERVO4_FUNCTION | 79 | S4: V-tail left (left tail panel).
SERVO5_FUNCTION | 80 | S5: V-tail right (right tail panel).
SERVO3_TRIM | 1500 | Aileron neutral. The 3 deg reflex is set mechanically on each link, not here (one servo moves the ailerons in opposite directions).
SERVO3_MIN | 1178 | About 10 deg aileron (servo 29 deg at 2.79:1). Verify: about 3.5 mm at the aileron trailing edge.
SERVO3_MAX | 1822 | As SERVO3_MIN. Linkage limit +-20 deg aileron = +-807 us: never set beyond it.
SERVO4_TRIM | 1500 | Left panel neutral; trim mechanically first (collar on the shaft flat).

# OUTPUTS

PARAMETER | VALUE | NOTE
SERVO4_MIN | 1232 | +-20 deg panel travel at 1.19:1 (servo 24 deg). Verify by measurement.
SERVO4_MAX | 1768 | As SERVO4_MIN.
SERVO5_TRIM | 1500 | Right panel neutral.
SERVO5_MIN | 1232 | As SERVO4_MIN.
SERVO5_MAX | 1768 | As SERVO4_MIN.
MIXING_GAIN | 0.5 | V-tail mix: full pitch alone gives half the panel travel (about +-10 deg), pitch plus yaw can reach the +-20 deg endpoints.
SERVO_RATE | 50 | Servo update rate (Hz) for the PWM groups; the ES9052MD is a digital servo and also accepts higher rates.

# MOTOR,ESCANDRPMTELEMETRY

Bidirectional DShot gives motor rpm in the logs: check on the thrust stand that the unloaded prop stays below 30,000 rpm on a full pack.

SERVO_DSHOT_ESC and the protocol depend on the ESC firmware (AM32 or BLHeli_32): verify on the bench.

PARAMETER | VALUE | NOTE
SERVO_BLH_MASK | 1 | DShot on output 1.
SERVO_BLH_OTYPE | 5 | DShot300. Verify the ESC accepts it.
SERVO_BLH_BDMASK | 1 | Bidirectional DShot (rpm telemetry) on output 1.
SERVO_BLH_POLES | 14 | Motor magnet poles (12N14P 2207 motors). Verify for your motor.
SERVO_DSHOT_ESC | 1 | BLHeli_32 / AM32 type ESC. Verify against your firmware version's list.
RPM1_TYPE | 5 | RPM sensor from ESC telemetry (logged).
RPM1_ESC_MASK | 1 | Motor on output 1.

# THROTTLE

THR_MAX is the prop-rating cap: no governor on the F405 yet: 30,000 / (2550 KV x 16.8 V) = 70 % keeps an unloaded prop on a full pack at its rating. Raise only when an rpm

governor is fitted and proven on the thrust stand.

Speed stages are held by a transmitter throttle limit on a switch (LAUNCH / STAGE, table below), not by the flight controller. ArduPilot clips the throttle at THR_MAX in the

stabilised modes; check on the bench that MANUAL is clipped too, otherwise fly the stages in FBWA.

PARAMETER | VALUE | NOTE
THR_MAX | 70 | no governor on the F405 yet: 30,000 / (2550 KV x 16.8 V) = 70 % keeps an unloaded prop on a full pack at its rating. Raise only when an rpm governor is fitted and proven on the thrust stand.
THR_MIN | 0 | Motor stops at zero throttle in flight (gliding, flutter abort).
THR_SLEWRATE | 100 | Throttle slew limit (% per second).
TRIM_THROTTLE | 35 | Cruise throttle guess for the synthetic-airspeed modes. Set from a log of level flight.

# NOAIRSPEEDSENSOR

No airspeed sensor is fitted. ArduPilot uses a synthetic airspeed from GPS, wind estimate and throttle; FBWA and MANUAL do not need it.

Stall is about 13.0 m/s; AIRSPEED_MIN keeps 25 % margin. AIRSPEED_MAX matches the first speed stage and is raised with the stages.

PARAMETER | VALUE | NOTE
ARSPD_TYPE | 0 | No airspeed sensor.
ARSPD_USE | 0 | Do not use an airspeed sensor.
AIRSPEED_MIN | 17 | m/s; 1.25 x the 13.0 m/s stall.
AIRSPEED_CRUISE | 20 | m/s; cruise target for CRUISE / FBWB / RTL.
AIRSPEED_MAX | 30 | m/s; stage 1. Raise with each stage the test plan clears.

# ATTITUDELIMITS,PITCHRATEANDYAWDAMPER

Pitch rate is limited per speed stage so a full pull stays under the 6 g limit (table below); the file holds stage 1 (94 deg/s). Lower it before each faster stage.

The flight-dynamics model finds the Dutch roll about neutral at 13 m/s, so the yaw damper is required. Start low and tune in flight.

PARAMETER | VALUE | NOTE
PTCH_RATE_MAX | 94 | deg/s, stage 1 (30 m/s). See the stage table.
ROLL_LIMIT_DEG | 55 | Bank limit in the stabilised modes.
PTCH_LIM_MAX_DEG | 25 | Nose-up limit.
PTCH_LIM_MIN_DEG | -25 | Nose-down limit (no steep powered dives: speed builds fast).
YAW2SRV_DAMP | 0.15 | Yaw damper gain, starting point. Increase in small steps if the tail wags.
KFF_RDDRMIX | 0.5 | Rudder (V-tail yaw) mixed with aileron for coordinated turns.

# RECEIVER,MODESANDARMING

RadioMaster RP1 V2 ELRS receiver on UART1 (TX1/RX1) with CRSF. Arm with a switch on channel 5; flight modes on channel 6.

Hand launch in FBWA with the LAUNCH throttle position; no auto-takeoff is needed.

PARAMETER | VALUE | NOTE
SERIAL1_PROTOCOL | 23 | RCIN (CRSF/ELRS) on UART1.
RC_OPTIONS | 8192 | Bit 13: 420k baud for ELRS.
RC5_OPTION | 153 | Channel 5 arms and disarms.
ARMING_RUDDER | 0 | No stick arming (switch only).
ARMING_CHECK | 1 | All pre-arm checks.
FLTMODE_CH | 6 | Flight-mode channel.
FLTMODE1 | 5 | FBWA (launch, stage runs).
FLTMODE2 | 5 | FBWA.
FLTMODE3 | 0 | MANUAL.

# RECEIVER,MODESANDARMING

PARAMETER | VALUE | NOTE
FLTMODE4 | 0 | MANUAL.
FLTMODE5 | 11 | RTL.
FLTMODE6 | 11 | RTL.

# GPSANDCOMPASS

TBS M10Q on UART3 (TX3/RX3, the GPS pads) with its QMC5883 compass on I2C (SDA/SCL). The GPS sits behind the battery: its compass is 3-6 cm from the battery leads.

Either calibrate and run compass-motor interference compensation (compassmot) on the thrust stand, or disable the compass and fly on GPS heading (COMPASS_USE 0).

PARAMETER | VALUE | NOTE
SERIAL3_PROTOCOL | 5 | GPS on UART3.
GPS_TYPE | 1 | Auto (u-blox M10). Named GPS1_TYPE in ArduPlane 4.6+.
COMPASS_ENABLE | 1 | Use the M10Q's compass (set 0 to fly without).
COMPASS_AUTODEC | 1 | Automatic declination.
COMPASS_AUTO_ROT | 2 | Detect the compass orientation during calibration. Verify the result against the GPS's arrow.

# BATTERYMONITORANDFAILSAFES

WING MINI PDB sensors: voltage divider 1K:10K, current 50 A/V. Calibrate both against a meter.

Radio failsafe: RTL after 5 s without signal. Low battery: RTL.

PARAMETER | VALUE | NOTE
BATT_MONITOR | 4 | Analog voltage and current.
BATT_VOLT_PIN | 10 | PDB voltage.
BATT_CURR_PIN | 11 | PDB current.
BATT_VOLT_MULT | 11.05 | Calibrate against a meter.
BATT_AMP_PERVLT | 50 | Calibrate against a meter or a known charge.
BATT_CAPACITY | 650 | mAh (4S 650).
BATT_LOW_VOLT | 13.6 | 3.4 V per cell under load.
BATT_LOW_MAH | 160 | About 25 % left.
BATT_FS_LOW_ACT | 1 | RTL on low battery.

# BATTERYMONITORANDFAILSAFES

PARAMETER | VALUE | NOTE
THR_FAILSAFE | 1 | Radio failsafe on.
FS_SHORT_ACTN | 0 | Short failsafe: circle (default).
FS_LONG_ACTN | 1 | Long failsafe: RTL.
FS_LONG_TIMEOUT | 5 | Seconds.

# OSDANDWIRELESSTELEMETRY

Analog OSD (board OSD chip) with ground speed, throttle, current, used capacity and voltage. ArduPilot has no ground-speed alarm: watch the ground-speed number against

the stage limit and judge speed from two-way passes.

DJI O4 noses: switch to MSP DisplayPort on UART5 (SERIAL5_PROTOCOL 42, OSD_TYPE 5).

The wireless USB extender is on UART6 (MAVLink2, 115200) for setup on the ground. PARAMETER | VALUE | NOTE
OSD_TYPE | 1 | Analog OSD. Use 5 (MSP DisplayPort) with the DJI O4 noses.
OSD1_ENABLE | 1 | Screen 1.
OSD1_GSPEED_EN | 1 | GPS ground speed.
OSD1_THROTTLE_EN | 1 | Throttle %.
OSD1_CURRENT_EN | 1 | Current.
OSD1_BATUSED_EN | 1 | Used capacity (mAh).
OSD1_BAT_VOLT_EN | 1 | Battery voltage.
OSD_W_BATVOLT | 14.0 | Battery voltage warning (V).
SERIAL6_PROTOCOL | 2 | MAVLink2 on UART6 (wireless board).

# OSDANDWIRELESSTELEMETRY

PARAMETER | VALUE | NOTE
SERIAL6_BAUD | 115 | 115200 baud.

# BENCHCHECKSBEFOREFLIGHT

Props off. Power from a full pack; check the battery voltage and current readings against a meter.

Control directions in MANUAL: right stick -> right aileron trailing edge up, left down. Pull -> both tail-panel trailing edges up. Right rudder -> left panel trailing edge down,

right panel up (inverted V, panels below the fuselage). Fix with SERVOx_REVERSED.

Measure deflections with a protractor: aileron about +-10 deg, tail panels +-20 deg at the endpoints; adjust SERVOx_MIN/MAX. Nothing binds or buzzes at the ends.

FBWA: roll and pitch the airframe by hand; the surfaces must oppose the motion.

Thrust stand: THR_MAX 70 %; logged rpm with the prop unloaded on a full pack below 30,000; ESC current within its rating.

Transmitter: LAUNCH / STAGE switch set to the stage limit; confirm in the servo-output screen that full stick on STAGE gives the stage %.

Radio failsafe: switch the transmitter off with the motor at low throttle (props off): motor stops or RTL behaviour as set.

Compass: calibrate, then compassmot on the thrust stand (or COMPASS_USE 0).

GPS: 3D fix and the OSD shows ground speed.

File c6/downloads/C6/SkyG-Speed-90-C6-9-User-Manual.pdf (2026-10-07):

# S KYG


# SKYGSPEED90

# USERMANUAL

REVISION C6-9 · 2026-10-07

# PACKAGECONTENTS

SkyG Speed 90 user manual (this document).

STL; pages in this manual).

Every printed part, in millimetres, ready for the slicer (print orientation:

Every printed part and the full assembly, for editing in any CAD program.

The wiring diagram as a separate large page.

Setup document and a starting .param file for the SpeedyBee F405 WING

Interactive 3D model (open the HTML file in a browser): every part exploded

Design record, parts list (BOM.csv), test plan and verification report.

SKY G | SKYG SPEED 90 | REVISION C6-9 · 2026-10-07 | USER MANUAL | 2

# TABLEOFCONTENTS

### Introduction

General aircraft data | 05
Aerodynamic design | 06
Aerodynamic characteristics | 07
Performance and speed stages | 08
Compartment layout | 10
Camera nose variants | 11

### Recommended equipment

Recommended electronics | 13
Recommended accessories | 14
Powertrain | 15

### Print settings

Print settings | 17
Parts list | 19
Parts orientation | 20

### Assembly guide

Fuselage assembly | 28
Wing assembly | 29
Tail module | 32
Equipment and wiring | 38
Camera nose | 41
Final assembly | 43
Finishing build | 44
Wiring diagram | 45
Electrical integration | 46
ArduPilot configuration | 49
Flight test and speed stages | 50
SKY G | SKYG SPEED 90 | USER MANUAL | 3

# SKYGSPEED90

SkyG Speed 90 is a compact, hand-launched speed aircraft: a 3D-

printed fuselage in three plug-together modules and a separate

camera nose, a 430 mm straight wing on a carbon spar, and an all-

moving canted tail driven by two micro servos. A single pusher motor

sits in the tail cone behind the tail.

The airframe is printed in foaming PLA Aero on a 0.4 mm nozzle; steel

and carbon parts carry the concentrated loads (spar, aileron hinge

pins and torque rods, tail shafts). Six interchangeable camera noses

take a micro FPV camera, a Raspberry Pi camera or a DJI O4 Air Unit,

each with an open or a clear-dome face.

It is built for straight-line speed: about 88 m/s finished with the

planned rpm governor, and about 64 m/s until that governor is fitted,

flown up through never-exceed stages.

SKY G | SKYG SPEED 90 | REVISION C6-9 · 2026-10-07 | USER MANUAL | 4

# GENERALAIRCRAFTDATA

Wingspan | 430 mm
Wing area | 3.65 dm²
Length | 451 mm
Centre of gravity | 9 mm behind the wing leading edge at the root
All-up weight | 396 g (micro-camera nose)
Stall speed | 13.0 m/s
Top speed (model) | 87–88 m/s with the governor
Airfoil | MH45, ailerons 3° reflex
Root / tip chord | 100 / 70 mm
MAC | 86 mm
Aspect ratio | 5.1
Wing loading | 104 g/dm²
SKY G | SKYG SPEED 90 | REVISION C6-9 · 2026-10-07 | USER MANUAL | 5

# AERODYNAMICDESIGN

The wing uses the MH45 section, a low-moment reflexed profile, with

both ailerons rigged 3° trailing edge up. The design CG is at 12 % of the

mean chord, 6.5 % static margin ahead of the neutral point (x 252 mm

from the nose datum): stable without a tail download penalty at speed.

Pitch and yaw come from two all-moving tail panels at 35° anhedral,

mixed like a V-tail, with a fixed fin on top. The Dutch roll is lightly

damped at low speed, so the flight controller's yaw damper is part of the

setup.

Flutter of the wing, ailerons and tail panels was analysed (strip theory

with the CAD-derived stiffness and masses): the lowest predicted

instability is 122 m/s, above 1.2 × the 90 m/s top stage. The test plan opens

the speed envelope in stages and measures the stiffness the margin

depends on.

SKY G | SKYG SPEED 90 | REVISION C6-9 · 2026-10-07 | USER MANUAL | 6

# AERODYNAMICCHARACTERISTICS


Whole aircraft, VSPAERO vortex lattice with the fuselage panels; best L/D 10.2 at 6.0°; Cm about the design CG.

SKY G | SKYG SPEED 90 | REVISION C6-9 · 2026-10-07 | USER MANUAL | 7

# PERFORMANCEANDSPEEDSTAGES

Motor | 2207 2550KV 4S racing motor
Propeller | APC 5x7.5E (LP05075E)
Battery | Tattu R-Line 4S 650 75C
Static thrust | 1064 g at 51 A (thrust / weight 2.69)
Throttle cap (prop rpm rating) | 70 %

Top speed

63–64 m/s now; 87–88 m/s with the

governor

Full-throttle time | about 0.7 min per pack (bursts of ≤ 10 s)
Stage Vne | STAGE throttle limit | Expected level speed
30 m/s | 27 % | 24 m/s
35 m/s | 32 % | 29 m/s
40 m/s | 36 % | 33 m/s
45 m/s | 41 % | 38 m/s
50 m/s | 45 % | 41 m/s
55 m/s | 50 % | 46 m/s
60 m/s | 54 % | 49 m/s
65 m/s | 59 % | 54 m/s
70 m/s | 64 % | 58 m/s
75 m/s | 69 % | 62 m/s
80 m/s | 70 % (needs the governor) | 63 m/s
85 m/s | 70 % (needs the governor) | 63 m/s
90 m/s | 70 % (needs the governor) | 63 m/s

No airspeed sensor: each stage is held by a throttle limit on a transmitter switch (LAUNCH =

full cap for the throw and climb-out only, STAGE = the limit). Level runs only; speed from

GPS two-way passes.

SKY G | SKYG SPEED 90 | REVISION C6-9 · 2026-10-07 | USER MANUAL | 8

# FILES


Every printed part is supplied as STL (for printing) and

STEP (for editing), plus the complete assembly as one

STEP file. Left and right wing halves, ailerons and tail

panels are separate files because they are mirror

images. The interactive viewer in the package shows

every part, purchased item and cable in place.

SKY G | SKYG SPEED 90 | REVISION C6-9 · 2026-10-07 | USER MANUAL | 9

# COMPARTMENTLAYOUT

BATTERY BAY; WING BAY; TAIL MODULE; NOSE BAY; nose; SKY G; SKYG SPEED 90; REVISION C6-9 · 2026-10-07; USER MANUAL

4S 650 pack, 60 × 31 × 21 mm max; slides x 98–130 for

balance; rear stop at x 160

Flight controller stack with the ESC on top, receiver,

aileron servo; reached with the wing off

Two tail servos, pushrods, horns and the motor; plugs off at

the MR30 and servo plugs

Camera and VTX (or the DJI O4 unit) in the removable

# CAMERANOSEVARIANTS

Nose | Camera | Battery centre for balance
N0M | 19 mm micro FPV camera + 20 × 20 VTX | x 113 mm
N0P | Raspberry Pi Camera Module 3 (test option) | x 91 mm (at its stop + nose ballast)
N0MD | micro camera behind a 40 mm dome, nano VTX under the hatch | x 111 mm
N0PD | Pi camera behind a dome | x 96 mm (at its stop + nose ballast)
N0O | DJI O4 Air Unit (Lite), ducted | x 118 mm
N0OD | DJI O4 behind a dome | x 120 mm
SKY G | SKYG SPEED 90 | REVISION C6-9 · 2026-10-07 | USER MANUAL | 11

# RECOMMENDEDEQUIPMENT

i

This section lists the electronics and parts needed to complete the

aircraft. The full list with order quantities, specifications and sources is

BOM.csv in the package.

SKY G | SKYG SPEED 90 | REVISION C6-9 · 2026-10-07 | USER MANUAL | 12

# RECOMMENDEDELECTRONICS

COMPONENT | MODEL / SPECIFICATION
Motor | 2207 2550KV 4S racing motor
Propeller (fixed) | APC 5x7.5E (LP05075E)
ESC | HDZero Halo 4in1 70A ESC AM32
Flight controller | SpeedyBee F405 WING MINI
GPS + compass | TBS M10Q GPS GLONASS (QMC5883 compass), 13.5 g
Servos | 3 × Emax ES9052MD or ES9052MD HV (Promodelhobby, Turkey)
Flight battery | Tattu R-Line 4S 650 75C (60 x 31 x 21 mm, 74 g)
Receiver | RadioMaster RP1 V2
FPV camera | Micro 19 mm FPV camera, e.g. RunCam Phoenix 2 or Caddx Ratel 2
Video transmitter + antenna | 20x20 analog or digital VTX with U.FL antenna
DJI O4 Air Unit (Lite) | DJI O4 Air Unit
SKY G | SKYG SPEED 90 | REVISION C6-9 · 2026-10-07 | USER MANUAL | 13

# RECOMMENDEDACCESSORIES

ITEM | QTY
XT30 connector pairs | 1
Carbon tube | 1
Music wire 2.0 mm | 2
Pushrods 1.2 mm with Z-bend | 4
Pushrod keepers for 1.2 mm wire | 4
Z-bend pliers, 1.1 mm drill, 1.2 mm drill (as a hand reamer), small flat file | 0
Nylon countersunk screw M3 x 16 | 1
M3 hex nut | 2
M2 x 6 countersunk screws (joints) | 6
Magnets 3x2 mm | 2
Magnets 3x1 mm | 2
Kapton / thin clear tape | as needed
Adhesives | as needed
Velcro strap + hook/loop | 1
ITEM | QTY
Heat shrink + silicone wire | as needed
Silver steel rod 2.5 mm | 2
Brass tube 3 mm | 2
MR30 connector pairs | 1
Servo extension leads 100 mm | 2
Motor screws M3 | 4
Glass skin + finish | 14 g
Nylon countersunk screw M3 x 12 | 1
M2 x 5 screws | 4
Servo strap / zip tie + foam tape | 1
Steel rod 1.5 mm | 2
Vent tape | 1
15T servo arms | 1
Dupont housings + crimps (1-pin, 4-pin) | 3
SKY G | SKYG SPEED 90 | REVISION C6-9 · 2026-10-07 | USER MANUAL | 14

# POWERTRAIN

i

Motor and prop. 2207 2550 KV class 4S racing motor (e.g. 2207 2550KV: 27.9-28 mm bell, about 21.5 mm body, 33.5 mm with the 5 mm prop shaft, 33 g, 16 x 16 mm M3).

Prop: APC 5 x 7.5E fixed thin-electric pusher (LP05075E, 5 mm bore, hub 12.7 x 7.1 mm, 30,000 rpm rating), rpm-governed at 29,500.

Throttle cap. A 5-inch prop is rated about 30,000 rpm. On a full 4S pack the unloaded prop would exceed it at full throttle, so the flight controller caps the throttle at

70 %. Never raise it, and inspect the blades after every thrust-stand run and flying day.

rpm governor (open item). This version is designed around a governor that holds the prop at 29,500 rpm, which lets it use the full rated rpm in level flight.

ArduPilot's governor script does not run on the F405 flight controller, so until an H7 flight controller or a governing ESC is fitted the throttle cap above applies and the

top speed is about 64 m/s; the 80–90 m/s stages need the governor.

Battery. Tattu R-Line 4S 650 75C (60 x 31 x 21 mm, 74 g); XT30. Full throttle in bursts of ≤ 10 s, then ≥ 30 s at low throttle: the ESC lives on its thermal mass. Static thrust in

the model: 1064 g at 51 A; confirm on a thrust stand before the first flight.

SKY G | SKYG SPEED 90 | REVISION C6-9 · 2026-10-07 | USER MANUAL | 15


# PRINTSETTINGS

SKY G | SKYG SPEED 90 | REVISION C6-9 · 2026-10-07 | USER MANUAL | 16

# PRINTSETTINGS

The airframe is designed for Bambu PLA Aero (foaming, lightweight) on a 0.4 mm nozzle and 0.20 mm layers; every part fits a Bambu H2S or H2D build volume.

The tail module may be printed in ASA Aero, the motor plate and spinner in PETG-CF.

GENERAL GUIDELINES

- Fuselage, nose and hatch shells: 2 walls, 30 % lightning infill (it only grows under top surfaces: at 0 % the solid bosses and bridges print hollow and their tops collapse).
- Wing halves and ailerons: 1 wall, 5 % gyroid.
- Tail panels: 2 walls, 10 % gyroid. Fin: 2 walls, 15 %.
- Motor plate and spinner: PETG-CF, 4 walls, 40 %.
- Tall standing parts: 5 mm brim, slow outer wall, enclosure door closed.

SUPPORTS: OFF

Every part is designed to print without supports in the orientation shown, and checked on the slicer's own G-code with these settings: nothing is printed over air and no bridge

is longer than 10 mm. Keep supports switched off and use the supplied .3mf files (they carry the settings). Ready-to-print sliced files for the Bambu Lab H2S and H2D with tree

supports switched on are also in the downloads (Bambu adds support only where a part needs it). Check the top of the aileron's torque-rod bore on the first aileron.

SKY G | SKYG SPEED 90 | REVISION C6-9 · 2026-10-07 | USER MANUAL | 17

# PRINTSETTINGS

FIRST PART AND WEIGHT CHECK; temperature, humidity and the enclosure.

Print F1 first and weigh it. If it is more than 15 % over the sliced mass (about 17 g), lower the PLA Aero temperature or flow before printing the rest; foaming filaments vary with

COUPON TESTS

Before the full build, print the last 25 mm of F1 with the first 25 mm of F2, and the F2/F3 and nose joints the same way: every joint must slide on and off by hand and the M2

screws must bite. Print a 40 mm wing-root section and check the spar fit.

SLICER; each part in the orientation shown.

The masses in this manual come from Bambu Studio with the H2S 0.4 mm profile and the walls/infill listed on the orientation pages. Import the STL files in millimetres; keep

SKY G | SKYG SPEED 90 | REVISION C6-9 · 2026-10-07 | USER MANUAL | 18

# PARTSLIST

PART | MATERIAL | MASS
N0M NOSE (MICRO FPV) | PLA Aero | 6.6 g
N0P NOSE (PI CAMERA) | PLA Aero | 6.2 g
N0MD NOSE (MICRO + DOME) | PLA Aero | 4.1 g
N0PD NOSE (PI + DOME) | PLA Aero | 4.6 g
N0O NOSE (DJI O4) | PLA Aero | 9.4 g
N0OD NOSE (DJI O4 + DOME) | PLA Aero | 7.4 g
F1 FUSELAGE FRONT | PLA Aero | 17.4 g
F2 FUSELAGE MAIN | PLA Aero | 22.5 g
F3 TAIL MODULE | ASA Aero | 7.6 g
HF FRONT HATCH | PLA Aero | 3.8 g
FN FIN | PLA Aero | 4.9 g
VTX SHELF (N0M) | PLA Aero | 0.5 g
DOME RING | PLA Aero | 0.5 g
HG GPS CARRIER | PLA Aero | 1.0 g
PART | MATERIAL | MASS
WR WING HALF RIGHT | PLA Aero | 17.1 g
WL WING HALF LEFT | PLA Aero | 17.1 g
AR AILERON RIGHT | PLA Aero | 2.5 g
AL AILERON LEFT | PLA Aero | 2.4 g
SR TAIL PANEL RIGHT | PLA Aero | 3.2 g
SL TAIL PANEL LEFT | PLA Aero | 3.2 g
M1 MOTOR PLATE | PETG-CF | 1.9 g
SP SPINNER | PETG-CF | 1.6 g

One aircraft with the N0M nose: 114 g printed. Only one camera nose is needed; the others

are options.

SKY G | SKYG SPEED 90 | REVISION C6-9 · 2026-10-07 | USER MANUAL | 19

# PARTSORIENTATION

N0PNOSE (PICAMERA); N0MDNOSE (MICRO + DOME); SKY G; SKYG SPEED 90; REVISION C6-9 · 2026-10-07; USER MANUAL

N0M NOSE (MICRO FPV)

FACE DOWN, SPIGOT UP

FRONT FACE DOWN

2 WALLS · 30 % INFILL · PLA AERO

# PARTSORIENTATION

N0PDNOSE (PI + DOME); N0O NOSE (DJIO4); FACE DOWN; N0ODNOSE (DJIO4 + DOME); SKY G; SKYG SPEED 90; REVISION C6-9 · 2026-10-07; USER MANUAL

FRONT FACE DOWN

2 WALLS · 30 % INFILL · PLA AERO

# PARTSORIENTATION

F1 FUSELAGE FRONT; F2 FUSELAGEMAIN; F3 TAIL MODULE; SKY G; SKYG SPEED 90; REVISION C6-9 · 2026-10-07; USER MANUAL

FRONT END DOWN · SPIGOT UP · 5 mm BRIM

FRONT END (SOCKET) DOWN · 5 mm BRIM

2 WALLS · 30 % INFILL · PLA AERO

2 WALLS · 30 % INFILL · ASA AERO

# PARTSORIENTATION

AR AILERON R / L; SKY G; SKYG SPEED 90; REVISION C6-9 · 2026-10-07; USER MANUAL

HF FRONT HATCH

WR WING HALF R / L

STANDING, FRONT END DOWN

ON THE ROOT RIB

ON THE INBOARD END

2 WALLS · 30 % INFILL · PLA AERO

1 WALLS · 5 % INFILL · PLA AERO

# PARTSORIENTATION

M1 MOTOR PLATE; FLAT; FN FIN; SKY G; SKYG SPEED 90; REVISION C6-9 · 2026-10-07; USER MANUAL

SR TAIL PANEL R / L

TIP DOWN, HUB UP

ON THE ROOT TAB

2 WALLS · 10 % INFILL · PLA AERO

4 WALLS · 40 % INFILL · PETG-CF

2 WALLS · 30 % INFILL · PLA AERO

# PARTSORIENTATION

SPSPINNER; BACKPLATE DOWN; VTX SHELF (N0M); FLAT; DOMERING; LIP DOWN; SKY G; SKYG SPEED 90; REVISION C6-9 · 2026-10-07; USER MANUAL

4 WALLS · 40 % INFILL · PETG-CF

2 WALLS · 30 % INFILL · PLA AERO

# PARTSORIENTATION


### HG GPSCARRIER

ON ITS REAR WALL

2 WALLS · 30 % INFILL · PLA AERO

SKY G | SKYG SPEED 90 | REVISION C6-9 · 2026-10-07 | USER MANUAL | 26


# ASSEMBLYGUIDE

SKY G | SKYG SPEED 90 | REVISION C6-9 · 2026-10-07 | USER MANUAL | 27

# FUSELAGEASSEMBLY

i

NOSE(N0M)

F1 FUSELAGEFRONT

F2FUSELAGEMAIN | F3 TAILMODULE

M2x6 SCREWS

The fuselage is four modules on spigot joints: the

camera nose, F1, F2 and the F3 tail module. Each

joint is held by two M2 × 6 countersunk screws from

the sides into bosses inside the spigot, their heads

flush in the countersinks; nothing is glued, so every

module comes off for service.

Clean any stringing from the spigots first. They must

slide in by hand.

M2 × 6 SCREWS

SKY G | SKYG SPEED 90 | REVISION C6-9 · 2026-10-07 | USER MANUAL | 28

# WINGASSEMBLY

i

WINGHALF R; WINGHALF L; 5x3x400 mmCARBONTUBE; dihedral).; EPOXY; SKY G; SKYG SPEED 90; REVISION C6-9 · 2026-10-07; USER MANUAL

Cut one 400 mm length of 5 × 3 mm carbon tube

and slide it through both wing halves (200 mm into

each). Epoxy the tube in the bores and the two root

ribs together with the whole wing flat on a table (0°

# WINGASSEMBLY

i

AILERON(AR)

1.5 mmHINGEPIN

WINGKNUCKLES

GLUEHOLES(CA)

Set each aileron in place: its rounded nose sits in

the cove along the wing's hinge face and the wing's

three knuckles enter the pockets in the nose. Push

a 132 mm length of 1.5 mm steel rod in from the

wingtip through the tip, the aileron and the

knuckles. Wick thin CA into the aileron's four glue

holes only, then plug the tip hole. The aileron must

swing freely.

THIN CA

SKY G | SKYG SPEED 90 | REVISION C6-9 · 2026-10-07 | USER MANUAL | 30

# WINGASSEMBLY

i

2.0 MMTORQUEROD

HORN+PIN

FLATTEDENDINTOTHEKNUCKLE(EPOXY)

Bend a 12 mm horn down at one end of each 2.0

mm rod with a 5.5 mm pin outboard at its tip, and

file a 0.3 mm flat on the last 9 mm of the straight

end, opposite the horn. Push it in from the root face

until the flat enters the D-bore of the aileron's root

knuckle; epoxy the end and hold the aileron 3°

trailing edge up while it cures.

EPOXY

SKY G | SKYG SPEED 90 | REVISION C6-9 · 2026-10-07 | USER MANUAL | 31

# TAILMODULE

i

TAILPANELL | TAILPANELR

SHAFT+COLLARHORN

3/32inBRASSBUSHINGS

Press a 10 mm brass bushing into each side boss of

F3. Epoxy a 2.5 mm steel shaft 35 mm into each tail

panel's root bore. From the open front of F3, push

each shaft through its bushing and fit the wheel-

collar horn with its 8 mm brass plate standing along

the panel's normal (not pointing forward), 0.5 mm

end play, set screw on a filed flat.

EPOXY

SKY G | SKYG SPEED 90 | REVISION C6-9 · 2026-10-07 | USER MANUAL | 32

# TAILMODULE

i

M1MOTORPLATE(BONDEDINTOTHESEAT)

22072550 CLASS4SRAC

SPINNER

PROP+M5

Bond the M1 plate into the conical seat at the rear of

F3 with high-temperature epoxy, its edge notches

lined up with the cooling windows; it is the motor

bulkhead. Then screw the motor to it with its 4 × M3

from inside the module, through the 28 mm

opening. Do this before the tail-panel shafts and

servos go in. Fit the spinner backplate, the prop

(APC 5 x 7.5E fixed thin-electric pusher (LP05075E, 5

mm bore, hub 12.7 x 7.1 mm, 30,000 rpm rating),

rpm-governed at 29,500) and the thin M5 nut.

EPOXY

SKY G | SKYG SPEED 90 | REVISION C6-9 · 2026-10-07 | USER MANUAL | 33

# TAILMODULE

ES9052MDSERVOS

15TARM(HOLEREAMED1.2mm)

1.2mmZ-BENDPUSHROD+KEEPER

PRINTEDHORN(ONTHESHAFTFLAT)

i

Stand both ES9052MD servos through the cut-outs

in the F3 floor on foam tape on the bottom skin, a

strap over them, output at the aft end, leads along

the side walls. One-sided 15T arm pointing

outboard; file a 0.3 mm flat on the inboard end of

each 2.5 mm stabilator shaft and epoxy the printed

horn (THR / THL) on it, arm along the panel's

normal. Drill the servo arm's 6.7 mm hole 1.1 mm

and ream it by hand with a 1.2 mm bit (and the

horn's hole the same): the wire must turn with no

play. 1.2 mm Z-bend pushrod: Z-bend in the arm,

90° L-bend at the horn end pushed outboard

through the horn's reamed hole, snap-on keeper on

the protruding end (unclip it to take the tail

module off). Free play at each panel trailing edge <=

0.2 mm. Check both panels move freely through

±20°.

SERVO TAPE

SKY G | SKYG SPEED 90 | REVISION C6-9 · 2026-10-07 | USER MANUAL | 34

# TAILMODULE

i

FNFIN; SLOT(CA); CA GLUE; SKY G; SKYG SPEED 90; REVISION C6-9 · 2026-10-07; USER MANUAL

Glue the fin into the top slot of F3 with CA, vertical

and square to the wing.

# FUSELAGEASSEMBLY

i

FRONTHATCH(HF)

TBSM10QGPS(PATCHUP)

Bond the printed GPS carrier (HG) under the rear of

the front hatch skin. Foam-tape the TBS M10Q GPS,

patch up, to its ceiling, against its rear ledge. The

hatch's pointed rear end reaches into F2 and its rear

screw goes into F2: take the hatch off before

separating F1 and F2. Press the magnets into the

hatch lips and the hatch, checking polarity. Leave a

slack loop in the GPS lead so the hatch lifts off.

FOAM TAPE

SKY G | SKYG SPEED 90 | REVISION C6-9 · 2026-10-07 | USER MANUAL | 36

# FUSELAGEASSEMBLY

i

4S650 mAhPACK; XT30 (BEHINDTHEPACK); REARSTOPRIBS; STRAPSLOTS; VELCRO STRAP; SKY G; SKYG SPEED 90; REVISION C6-9 · 2026-10-07; USER MANUAL

The pack sits on the F1 floor with a strap through the

slots, leads at its rear. Two floor ribs are its rear stop;

the XT30 pair lies behind the pack under the GPS

and unplugs through the front hatch.

# EQUIPMENT

i

SPEEDYBEEF405 WINGMINI; ESC(ONTHESTACK); 1RECEIVER; T-ANTENNA; AILERONSERVO; aft end.; FOAM TAPE; SKY G; SKYG SPEED 90; REVISION C6-9 · 2026-10-07; USER MANUAL

SpeedyBee F405 WING MINI stack on foam tape

and a strap on the wing-bay floor, arrow forward,

servo BEC jumper at 6 V; the ESC on top of the stack

on a foam pad. Receiver ahead of it, its T-antenna as

an L at x≈220 (one leg up the left wall, one across

the floor). Aileron servo aft of the stack, output at the

# EQUIPMENT

TWO-S1ID.2EmDm15ZT-BAERNMD(PRUESAHMREODD1S.2+mKmEE)PERS

PRINTEDHORNONTHEBENTLEG

TORQUERODS(ONE90 degBEND)

i

ES9052MD aileron servo standing through the

wing-bay floor on foam tape; two-sided 15T arm.

Each torque rod has one 90° bend (the horn leg, 6

mm from the centreline); epoxy the printed horn

(AHR / AHL) on the leg, 4 mm deep. Drill the arm's

4.3 mm holes 1.1 mm and ream them by hand with

a 1.2 mm bit (and both horns' holes): the wire must

turn with no play. Each horn connects to the arm

with a 1.2 mm Z-bend pushrod: Z-bend in the arm,

90° L-bend pushed inboard through the horn's

reamed hole, snap-on keeper on the protruding

end. Check: with the servo powered, each aileron

trailing edge moves <= 0.2 mm (free play lowers

aileron flutter to about 33 m/s). Set both ailerons 3°

trailing edge up at servo neutral. No play at either

end.

Z-BENDS

SKY G | SKYG SPEED 90 | REVISION C6-9 · 2026-10-07 | USER MANUAL | 39

# EQUIPMENT

XT30

MR30 (MOTOR)

SERVOPLUGPAIRS

VIDEOTRUNK(UNDERTHEFLOOR)

GPSLEAD

MOTORLEADS

i

ESC flat on its foam tape at the bottom of the wing

bay, receiver on top of it, FC stack 5 mm behind it

(servo header row on the right). Battery lead (14

AWG) from the XT30 over the ESC and down the

gap to the FC power board's BAT pads; 14 AWG ESC

feed from its ESC pads up onto the ESC; ESC signal

(M1, GND, TLM) and receiver lead up the gap to the

FC; motor phases up the gap, over the FC's left half

to the MR30; the ELRS coax under the wing-screw

bridges to the u.FL joint ahead of the tail joint and

up into the fin. Cut lengths and lanes: Electrical

Integration manual. Unplug the MR30, the u.FL

joint and the servo plugs before pulling the tail

module.

HEAT SHRINK

SKY G | SKYG SPEED 90 | REVISION C6-9 · 2026-10-07 | USER MANUAL | 40

# CAMERANOSE

19 mmFPV CAMERA

2xM2x10 +WASHERS

VTXONTHESHELF

VIDEOANTENNA(CLIPS)

i

Slide the 19 mm camera in from the open rear until

the lens reaches the face; 2 × M2 × 8 pan head + 2 ×

M2 washer (5 mm OD) through the side seats, lens

flush, tilt 0–10° up. Fix the VTX to the printed VTX

shelf (foam tape + zip tie through its slots), slide the

shelf in from the rear onto its two rails and glue it;

video antenna in the two clips on the right wall.

Plug the one lead at the nose joint. Dome noses:

glue the printed dome ring 3 mm into the front of

the tube, then fit the clear dome over its lip with

canopy glue (no CA).

FOAM TAPE

SKY G | SKYG SPEED 90 | REVISION C6-9 · 2026-10-07 | USER MANUAL | 41

# CAMERANOSE

i

DJIO4CAMERA(INITSMOUNT); O4MODULE(INTOTHEDUCT); ANTENNASLOT; M2 × 5 SCREWS; SKY G; SKYG SPEED 90; REVISION C6-9 · 2026-10-07; USER MANUAL

DJI O4 option: clamp the camera in its mount with

4 × M2 × 5 through the side slots (at most 3.1 mm

into the mount). Plug the coax and 3-in-1 lead into

the module and slide it edge-first into the duct

until it stops; foam strip in the top groove, tape over

the rear edge, never over its faces.

# FINALASSEMBLY

i

WING; M3x16 NYLON(FRONT); M3x12NYLON(REAR); countersinks.; NYLON SCREWS; SKY G; SKYG SPEED 90; REVISION C6-9 · 2026-10-07; USER MANUAL

Push an M3 nut up into each bolt-bridge pocket in

F2. Set the wing on the saddle and bolt it with the

nylon screws: Countersunk M3 × 16 at the front,

countersunk M3 × 12 at the rear (LE + 58, ahead of

the aileron horns); the heads sit flush in the

# FINISHINGBUILD

i

Before the first flight: every control surface moves the right way (pitch up: both

panel trailing edges up; right roll: right aileron up), throws ±10° on the tail panels,

about ±10° (±3.5 mm at the trailing edge) on the ailerons, 30 % expo; the prop turns

the right way and pushes aft; failsafe set to motor off.

Balance: CG 9 mm behind the wing leading edge at the root (mark it on the wing

underside). Slide the battery to trim; for the first flight set the CG 2 mm forward. If a

heavy camera needs it, use the nose or tail ballast cup.

Glass skin: one ±45° layer of 49 g/m² glass on the wing halves and tail panels after

printing, then a thin paint finish.

SKY G | SKYG SPEED 90 | REVISION C6-9 · 2026-10-07 | USER MANUAL | 44

# WIRINGDIAGRAM

i

S1

THROTTLE(MOTORESC)

S3

AILERON

S4

V-TAILLEFT

S5

V-TAILRIGHT

FC

RX (UART1)

GPS (UART3)

4S PACK

MOTOR

The diagram shows the flight-controller outputs and where each device sits.

Signal, power and video leads follow the routes on the wiring page of the

assembly guide; the package has this diagram as a separate large page.

PAD | FUNCTION | DEVICE
S1 | Throttle (motor ESC) | ESC (DShot300, bidirectional)
S2 | Unused | Leave empty (DShot group with S1)
S3 | Aileron | Aileron servo (ES9052MD, wing bay)
S4 | V-tail left | Left tail-panel servo (ES9052MD, tail module)
S5 | V-tail right | Right tail-panel servo (ES9052MD, tail module)
SKY G | SKYG SPEED 90 | REVISION C6-9 · 2026-10-07 | USER MANUAL | 45

# ELECTRICAL INTEGRATION

Battery → FC power board (80 A current sensor) → ESC (motor on M1) → MR30 at the tail joint → motor. Main DC path 14 AWG (46 A on a pass, 51 A static), motor phases 16 AWG (38 A

RMS). Cable lengths are measured on the 3D harness model; the cut list adds the termination allowances and slack. Full detail, pinouts, settings and tests: the Electrical Integration

manual (PDF in the package and on the web page).

ID | CABLE | FROM | TO | AWG | CUT mm
W01 | Battery lead | XT30 female (the pack plugs in), behind the pack under… | FC power board BAT+ / BAT- pads | 14 | 110
W02 | ESC feed | FC power board ESC+ / ESC- pads | HDZero Halo 4in1 70A ESC AM32 BAT+ / BAT- pads (XT60… | 14 | 35
W03 | Motor phases, ESC side | HDZero Halo 4in1 70A ESC AM32 M1 pads (A, B, C) | MR30 female (ESC side), low on the left ahead of the… | 16 | 95
W04 | Motor phases, motor side | MR30 male | Motor phase wires (cut to 20 mm, butt-soldered + heat… | 16 | 140
W05 | ESC signal | HDZero Halo 4in1 70A ESC AM32 8-pin SH1.0 lead (only M1,… | FC S1 header (signal, GND); TLM to the R4 pad | 28 | 45
W06 | Receiver lead | RadioMaster RP1 V2 pads (5V, GND, TX, RX), on the ESC | FC receiver header (5V, GND, RX1, TX1) | 28 | 45
W07 | ELRS antenna coax | RP1 V2 u.FL | Dipole feed at the centre of the fin dipole (z 39.5) | coax | 265
W08 | GPS lead | TBS M10Q (VCC, GND, TX, RX, SDA, SCL) | FC GPS interface with compass (4V5, GND, RX3, TX3, SDA,… | 28 | 115
W09 | Video trunk (N0M nose) | Nose joint plug (camera on the nose; VTX on the nose or,… | FC pads: Vv, G, C1 (camera in), VTX (video out) | 28 | 265
W10 | Tail servo leads (L, R) | Emax ES9052MD in F3 (its stock lead) | JR plug pair lying flat beside the aileron servo | 26 | stock
W12 | Tail servo extensions (L, R) | JR plug pair (beside the aileron servo) | FC S4 (left) / S5 (right) | 26 | stock
W11 | Aileron servo lead | Emax ES9052MD lead (stock), aileron servo in the wing bay | FC S3 header | 26 | stock
SKY G | SKYG SPEED 90 | REVISION C6-9 · 2026-10-07 | USER MANUAL | 46

# ELECTRICAL:POWERANDROUTING


CABLE | CIRCUIT | CURRENT A (PASS / STATIC) | WIRE | DROP V | dT K / PASS | CONNECTOR RATING
W01+W02 | Battery to ESC (DC) | 46 / 51 | 14 AWG | 0.07 (0.5 %) | 20 | XT30: 15 A cont / 30 A peak (see open item)
W03+W04 | Motor phases (per phase, RMS) | 38 / 42 | 16 AWG | 0.17 (1.1 %) | 33 | MR30: 30 A cont / 40 A for 1 min per contact

XT30: rated 15 A continuous / 30 A peak. Flown as the test base (70 % throttle cap, no governor) the pack draws about 18 A: fine. Only with the governor fitted (46–51 A) does it need an

XT60 lead and a ready-made XT60 pack. Never connect the ESC lead's VBAT pin to the FC's servo header or a 5 V pad. Power-board jumpers: servo BEC 6 V; Vv battery voltage only if

the camera and VTX accept 4S.

SKY G | SKYG SPEED 90 | REVISION C6-9 · 2026-10-07 | USER MANUAL | 47

# ELECTRICAL:RECEIVERANTENNA

i

The receiver's antenna is a vertical dipole inside the fin, clear of

all metal: the RP1 V2 T-antenna's two 31 mm legs lie in a groove

on the fin's 30 % chord line with the T's joint (the feed) at the

centre. The antenna's own coax runs down a parallel groove

beside the lower leg into the tail module, to an in-line u.FL joint

just ahead of the tail joint; a 1.13 mm u.FL extension continues to

the receiver on the ESC. Unplug the u.FL joint with the MR30

and the servo plugs before pulling the tail module. Lay antenna

and coax in the grooves before the fin is glued; three dots of

epoxy, tape over the grooves.

SKY G | SKYG SPEED 90 | REVISION C6-9 · 2026-10-07 | USER MANUAL | 48

# ARDUPILOTCONFIGURATION

Starting ArduPlane configuration for SkyG Speed 90 on the SpeedyBee F405 WING MINI (firmware

target SpeedyBeeF405WING, ArduPlane 4.5 or later). Load the .param file in Mission Planner (Config >

Full Parameter List > Load from file), then work through the bench checks.

Flight controller: on the wing-bay floor, arrow forward; servo BEC jumper set to 6 V for the ES9052MD

servos.

Firmware: ArduPlane 4.5 or later · Board: SpeedyBee F405 WING MINI (ArduPilot target:

SpeedyBeeF405WING)

The setup document and the starting .param file are in the package (ArduPilot folder). Verify every

value on the bench before flight.

## S KY G

# ARDUPILOTCONFIG

## SKYG SPEED 90

### SPEEDYBEE F405 WING MINI

SKY G | SKYG SPEED 90 | REVISION C6-9 · 2026-10-07 | USER MANUAL | 49

# FLIGHTTESTANDSPEEDSTAGES

i

The speed envelope opens in stages. Fly each stage only after the

ground checks and the previous stage pass: thrust-stand run, wing

load and twist test, control freeplay ≤ 0.2 mm (≤ 0.05 mm above 45

m/s), aileron hinge stiffness, and the tap test. At each run give short

aileron and pitch doublets; any buzz or vibration: throttle to zero,

gentle pull-up, land and inspect.

Full procedure, limits and log sheet: the test plan in the Engineering

folder.

Stage Vne | STAGE throttle limit | Expected level speed
30 m/s | 27 % | 24 m/s
35 m/s | 32 % | 29 m/s
40 m/s | 36 % | 33 m/s
45 m/s | 41 % | 38 m/s
50 m/s | 45 % | 41 m/s
55 m/s | 50 % | 46 m/s
60 m/s | 54 % | 49 m/s
65 m/s | 59 % | 54 m/s
70 m/s | 64 % | 58 m/s
75 m/s | 69 % | 62 m/s
80 m/s | 70 % (needs the governor) | 63 m/s
85 m/s | 70 % (needs the governor) | 63 m/s
90 m/s | 70 % (needs the governor) | 63 m/s
SKY G | SKYG SPEED 90 | REVISION C6-9 · 2026-10-07 | USER MANUAL | 50

# S KYG

# SKYGSPEED90

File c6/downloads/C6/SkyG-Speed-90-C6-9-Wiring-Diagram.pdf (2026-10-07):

# WIRINGDIAGRAM·SKYGSPEED90


S1

THROTTLE(MOTORESC)

S3

AILERON

S4

V-TAILLEFT

S5

V-TAILRIGHT

FC

RX (UART1)

GPS (UART3)

4S PACK

MOTOR

PAD | FUNCTION | DEVICE
S1 | Throttle (motor ESC) | ESC (DShot300, bidirectional)
S2 | Unused | Leave empty (DShot group with S1)
S3 | Aileron | Aileron servo (ES9052MD, wing bay)
S4 | V-tail left | Left tail-panel servo (ES9052MD, tail module)
S5 | V-tail right | Right tail-panel servo (ES9052MD, tail module)
PORT | DEVICE | SETTING
UART1 (TX1/RX1) / SERIAL1 | RadioMaster RP1 V2 ELRS receiver | SERIAL1_PROTOCOL = 23
UART3 (TX3/RX3) / SERIAL3 | TBS M10Q GPS (compass on SDA/SCL) | SERIAL3_PROTOCOL = 5
UART5 (TX5/RX5) / SERIAL5 | DJI O4 Air Unit (O4 noses only) | SERIAL5_PROTOCOL = 42 (O4 noses)
UART6 / SERIAL6 | Wireless USB extender (ground setup) | SERIAL6_PROTOCOL = 2

SKYG SPEED 90 · REVISION C6-9 · 2026-10-07

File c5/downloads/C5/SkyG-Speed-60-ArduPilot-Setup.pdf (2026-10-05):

# S KYG

# ARDUPILOTCONFIG

# SKYGSPEED60

SpeedyBee F405 WING MINI (ArduPilot target: SpeedyBeeF405WING) · ArduPlane 4.5 or later

# OVERVIEW


Starting ArduPlane configuration for SkyG Speed 60 on the SpeedyBee F405 WING MINI (firmware target SpeedyBeeF405WING, ArduPlane 4.5 or later). Load the .param

file in Mission Planner (Config > Full Parameter List > Load from file), then work through the bench checks.

Flight controller: on the wing-bay floor, arrow forward; servo BEC jumper set to 6 V for the ES9052MD servos.

WARNINGS

These are starting values, not a tested setup. Verify every output, direction and endpoint on the bench before the first flight.

Never raise THR_MAX: it protects the prop's rpm rating.

No airspeed sensor: the throttle limits do not stop a dive from building speed. Fly stage runs level.

# FRAME,ORIENTATIONANDLOGGING

PARAMETER; VALUE; NOTE; LOG_BACKEND_TYPE; Logs to the microSD card.; LOG_DISARMED; No logging while disarmed.

Board mounted on the wing-bay floor, arrow forward, components up (build guide). Log to the microSD card.

AHRS_ORIENTATION | 0 | FC arrow forward, upright. Change only if the board is mounted otherwise.

# OUTPUTS

S1 drives the motor with bidirectional DShot (rpm telemetry for the prop-rpm check). S1 and S2 form one timer group: S2 stays unused. S3 drives the single aileron servo (both

ailerons through the torque rods). S4 and S5 drive the left and right tail panels as a V-tail mix.

Servo endpoints are calculated for the Emax ES9052MD (about 11.1 us per degree) and the linkages: aileron 2.79:1 (12 mm horn, 4.3 mm arm hole), tail 1.19:1 (8 mm horn, 6.7 mm

arm hole). They are starting points: set the final values by measuring the deflections on the bench.

PARAMETER | VALUE | NOTE
SERVO1_FUNCTION | 70 | S1: throttle (motor ESC).
SERVO2_FUNCTION | 0 | S2: unused (shares the DShot timer group with S1).
SERVO3_FUNCTION | 4 | S3: aileron (one servo drives both ailerons).
SERVO4_FUNCTION | 79 | S4: V-tail left (left tail panel).
SERVO5_FUNCTION | 80 | S5: V-tail right (right tail panel).
SERVO3_TRIM | 1500 | Aileron neutral. The 3 deg reflex is set mechanically on each link, not here (one servo moves the ailerons in opposite directions).
SERVO3_MIN | 1178 | About 10 deg aileron (servo 29 deg at 2.79:1). Verify: about 3.5 mm at the aileron trailing edge.
SERVO3_MAX | 1822 | As SERVO3_MIN. Linkage limit +-20 deg aileron = +-807 us: never set beyond it.
SERVO4_TRIM | 1500 | Left panel neutral; trim mechanically first (collar on the shaft flat).

# OUTPUTS

PARAMETER | VALUE | NOTE
SERVO4_MIN | 1232 | +-20 deg panel travel at 1.19:1 (servo 24 deg). Verify by measurement.
SERVO4_MAX | 1768 | As SERVO4_MIN.
SERVO5_TRIM | 1500 | Right panel neutral.
SERVO5_MIN | 1232 | As SERVO4_MIN.
SERVO5_MAX | 1768 | As SERVO4_MIN.
MIXING_GAIN | 0.5 | V-tail mix: full pitch alone gives half the panel travel (about +-10 deg), pitch plus yaw can reach the +-20 deg endpoints.
SERVO_RATE | 50 | Servo update rate (Hz) for the PWM groups; the ES9052MD is a digital servo and also accepts higher rates.

# MOTOR,ESCANDRPMTELEMETRY

Bidirectional DShot gives motor rpm in the logs: check on the thrust stand that the unloaded prop stays below 30,000 rpm on a full pack.

SERVO_DSHOT_ESC and the protocol depend on the ESC firmware (AM32 or BLHeli_32): verify on the bench.

PARAMETER | VALUE | NOTE
SERVO_BLH_MASK | 1 | DShot on output 1.
SERVO_BLH_OTYPE | 5 | DShot300. Verify the ESC accepts it.
SERVO_BLH_BDMASK | 1 | Bidirectional DShot (rpm telemetry) on output 1.
SERVO_BLH_POLES | 14 | Motor magnet poles (12N14P 2207 motors). Verify for your motor.
SERVO_DSHOT_ESC | 1 | BLHeli_32 / AM32 type ESC. Verify against your firmware version's list.
RPM1_TYPE | 5 | RPM sensor from ESC telemetry (logged).
RPM1_ESC_MASK | 1 | Motor on output 1.

# THROTTLE

THR_MAX is the prop-rating cap: prop rpm rating: 30,000 / (2150 KV x 16.8 V) = 83 %. Never raise it.

Speed stages are held by a transmitter throttle limit on a switch (LAUNCH / STAGE, table below), not by the flight controller. ArduPilot clips the throttle at THR_MAX in the

stabilised modes; check on the bench that MANUAL is clipped too, otherwise fly the stages in FBWA.

PARAMETER | VALUE | NOTE
THR_MAX | 83 | prop rpm rating: 30,000 / (2150 KV x 16.8 V) = 83 %. Never raise it.
THR_MIN | 0 | Motor stops at zero throttle in flight (gliding, flutter abort).
THR_SLEWRATE | 100 | Throttle slew limit (% per second).
TRIM_THROTTLE | 35 | Cruise throttle guess for the synthetic-airspeed modes. Set from a log of level flight.

# NOAIRSPEEDSENSOR

No airspeed sensor is fitted. ArduPilot uses a synthetic airspeed from GPS, wind estimate and throttle; FBWA and MANUAL do not need it.

Stall is about 12.6 m/s; AIRSPEED_MIN keeps 25 % margin. AIRSPEED_MAX matches the first speed stage and is raised with the stages.

PARAMETER | VALUE | NOTE
ARSPD_TYPE | 0 | No airspeed sensor.
ARSPD_USE | 0 | Do not use an airspeed sensor.
AIRSPEED_MIN | 16 | m/s; 1.25 x the 12.6 m/s stall.
AIRSPEED_CRUISE | 20 | m/s; cruise target for CRUISE / FBWB / RTL.
AIRSPEED_MAX | 30 | m/s; stage 1. Raise with each stage the test plan clears.

# ATTITUDELIMITS,PITCHRATEANDYAWDAMPER

Pitch rate is limited per speed stage so a full pull stays under the 6 g limit (table below); the file holds stage 1 (94 deg/s). Lower it before each faster stage.

The flight-dynamics model finds the Dutch roll about neutral at 13 m/s, so the yaw damper is required. Start low and tune in flight.

PARAMETER | VALUE | NOTE
PTCH_RATE_MAX | 94 | deg/s, stage 1 (30 m/s). See the stage table.
ROLL_LIMIT_DEG | 55 | Bank limit in the stabilised modes.
PTCH_LIM_MAX_DEG | 25 | Nose-up limit.
PTCH_LIM_MIN_DEG | -25 | Nose-down limit (no steep powered dives: speed builds fast).
YAW2SRV_DAMP | 0.15 | Yaw damper gain, starting point. Increase in small steps if the tail wags.
KFF_RDDRMIX | 0.5 | Rudder (V-tail yaw) mixed with aileron for coordinated turns.

# RECEIVER,MODESANDARMING

RadioMaster RP1 V2 ELRS receiver on UART1 (TX1/RX1) with CRSF. Arm with a switch on channel 5; flight modes on channel 6.

Hand launch in FBWA with the LAUNCH throttle position; no auto-takeoff is needed.

PARAMETER | VALUE | NOTE
SERIAL1_PROTOCOL | 23 | RCIN (CRSF/ELRS) on UART1.
RC_OPTIONS | 8192 | Bit 13: 420k baud for ELRS.
RC5_OPTION | 153 | Channel 5 arms and disarms.
ARMING_RUDDER | 0 | No stick arming (switch only).
ARMING_CHECK | 1 | All pre-arm checks.
FLTMODE_CH | 6 | Flight-mode channel.
FLTMODE1 | 5 | FBWA (launch, stage runs).
FLTMODE2 | 5 | FBWA.
FLTMODE3 | 0 | MANUAL.

# RECEIVER,MODESANDARMING

PARAMETER | VALUE | NOTE
FLTMODE4 | 0 | MANUAL.
FLTMODE5 | 11 | RTL.
FLTMODE6 | 11 | RTL.

# GPSANDCOMPASS

TBS M10Q on UART3 (TX3/RX3, the GPS pads) with its QMC5883 compass on I2C (SDA/SCL). The GPS sits behind the battery: its compass is 3-6 cm from the battery leads.

Either calibrate and run compass-motor interference compensation (compassmot) on the thrust stand, or disable the compass and fly on GPS heading (COMPASS_USE 0).

PARAMETER | VALUE | NOTE
SERIAL3_PROTOCOL | 5 | GPS on UART3.
GPS_TYPE | 1 | Auto (u-blox M10). Named GPS1_TYPE in ArduPlane 4.6+.
COMPASS_ENABLE | 1 | Use the M10Q's compass (set 0 to fly without).
COMPASS_AUTODEC | 1 | Automatic declination.
COMPASS_AUTO_ROT | 2 | Detect the compass orientation during calibration. Verify the result against the GPS's arrow.

# BATTERYMONITORANDFAILSAFES

WING MINI PDB sensors: voltage divider 1K:10K, current 50 A/V. Calibrate both against a meter.

Radio failsafe: RTL after 5 s without signal. Low battery: RTL.

PARAMETER | VALUE | NOTE
BATT_MONITOR | 4 | Analog voltage and current.
BATT_VOLT_PIN | 10 | PDB voltage.
BATT_CURR_PIN | 11 | PDB current.
BATT_VOLT_MULT | 11.05 | Calibrate against a meter.
BATT_AMP_PERVLT | 50 | Calibrate against a meter or a known charge.
BATT_CAPACITY | 650 | mAh (4S 650).
BATT_LOW_VOLT | 13.6 | 3.4 V per cell under load.
BATT_LOW_MAH | 160 | About 25 % left.
BATT_FS_LOW_ACT | 1 | RTL on low battery.

# BATTERYMONITORANDFAILSAFES

PARAMETER | VALUE | NOTE
THR_FAILSAFE | 1 | Radio failsafe on.
FS_SHORT_ACTN | 0 | Short failsafe: circle (default).
FS_LONG_ACTN | 1 | Long failsafe: RTL.
FS_LONG_TIMEOUT | 5 | Seconds.

# OSDANDWIRELESSTELEMETRY

Analog OSD (board OSD chip) with ground speed, throttle, current, used capacity and voltage. ArduPilot has no ground-speed alarm: watch the ground-speed number against

the stage limit and judge speed from two-way passes.

DJI O4 noses: switch to MSP DisplayPort on UART5 (SERIAL5_PROTOCOL 42, OSD_TYPE 5).

The wireless USB extender is on UART6 (MAVLink2, 115200) for setup on the ground. PARAMETER | VALUE | NOTE
OSD_TYPE | 1 | Analog OSD. Use 5 (MSP DisplayPort) with the DJI O4 noses.
OSD1_ENABLE | 1 | Screen 1.
OSD1_GSPEED_EN | 1 | GPS ground speed.
OSD1_THROTTLE_EN | 1 | Throttle %.
OSD1_CURRENT_EN | 1 | Current.
OSD1_BATUSED_EN | 1 | Used capacity (mAh).
OSD1_BAT_VOLT_EN | 1 | Battery voltage.
OSD_W_BATVOLT | 14.0 | Battery voltage warning (V).
SERIAL6_PROTOCOL | 2 | MAVLink2 on UART6 (wireless board).

# OSDANDWIRELESSTELEMETRY

PARAMETER | VALUE | NOTE
SERIAL6_BAUD | 115 | 115200 baud.

# BENCHCHECKSBEFOREFLIGHT

Props off. Power from a full pack; check the battery voltage and current readings against a meter.

Control directions in MANUAL: right stick -> right aileron trailing edge up, left down. Pull -> both tail-panel trailing edges up. Right rudder -> left panel trailing edge down,

right panel up (inverted V, panels below the fuselage). Fix with SERVOx_REVERSED.

Measure deflections with a protractor: aileron about +-10 deg, tail panels +-20 deg at the endpoints; adjust SERVOx_MIN/MAX. Nothing binds or buzzes at the ends.

FBWA: roll and pitch the airframe by hand; the surfaces must oppose the motion.

Thrust stand: THR_MAX 83 %; logged rpm with the prop unloaded on a full pack below 30,000; ESC current within its rating.

Transmitter: LAUNCH / STAGE switch set to the stage limit; confirm in the servo-output screen that full stick on STAGE gives the stage %.

Radio failsafe: switch the transmitter off with the motor at low throttle (props off): motor stops or RTL behaviour as set.

Compass: calibrate, then compassmot on the thrust stand (or COMPASS_USE 0).

GPS: 3D fix and the OSD shows ground speed.

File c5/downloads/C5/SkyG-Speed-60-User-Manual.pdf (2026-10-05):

# S KYG


# SKYGSPEED60

# USERMANUAL

V.1 · C5-9 · 2026-10-01

# PACKAGECONTENTS

SkyG Speed 60 user manual (this document).

STL; pages in this manual).

Every printed part, in millimetres, ready for the slicer (print orientation:

Every printed part and the full assembly, for editing in any CAD program.

The wiring diagram as a separate large page.

Setup document and a starting .param file for the SpeedyBee F405 WING

Interactive 3D model (open the HTML file in a browser): every part exploded

Design record, parts list (BOM.csv), test plan and verification report.

SKY G | SKYG SPEED 60 | USER MANUAL | 2

# TABLEOFCONTENTS

### Introduction

General aircraft data | 05
Aerodynamic design | 06
Aerodynamic characteristics | 07
Performance and speed stages | 08
Compartment layout | 10
Camera nose variants | 11

### Recommended equipment

Recommended electronics | 13
Recommended accessories | 14
Powertrain | 15

### Print settings

Print settings | 17
Parts list | 19
Parts orientation | 20

### Assembly guide

Fuselage assembly | 28
Wing assembly | 29
Tail module | 32
Equipment and wiring | 38
Camera nose | 41
Final assembly | 43
Finishing build | 44
Wiring diagram | 45
ArduPilot configuration | 46
Flight test and speed stages | 47
SKY G | SKYG SPEED 60 | USER MANUAL | 3

# SKYGSPEED60

SkyG Speed 60 is a compact, hand-launched speed aircraft: a 3D-

printed fuselage in three plug-together modules and a separate

camera nose, a 430 mm straight wing on a carbon spar, and an all-

moving canted tail driven by two micro servos. A single pusher motor

sits in the tail cone behind the tail.

The airframe is printed in foaming PLA Aero on a 0.4 mm nozzle; steel

and carbon parts carry the concentrated loads (spar, aileron hinge

pins and torque rods, tail shafts). Six interchangeable camera noses

take a micro FPV camera, a Raspberry Pi camera or a DJI O4 Air Unit,

each with an open or a clear-dome face.

It is built for straight-line speed: about 62 m/s as printed and 65 m/s

finished in the model, flown up through never-exceed stages to 60

m/s.

SKY G | SKYG SPEED 60 | USER MANUAL | 4

# GENERALAIRCRAFTDATA

Wingspan | 430 mm
Wing area | 3.65 dm²
Length | 449 mm
Centre of gravity | 9 mm behind the wing leading edge at the root
All-up weight | 360 g (micro-camera nose)
Stall speed | 12.6 m/s
Top speed (model) | 62–65 m/s
Airfoil | MH45, ailerons 3° reflex
Root / tip chord | 100 / 70 mm
MAC | 86 mm
Aspect ratio | 5.1
Wing loading | 98 g/dm²
SKY G | SKYG SPEED 60 | USER MANUAL | 5

# AERODYNAMICDESIGN

The wing uses the MH45 section, a low-moment reflexed profile, with

both ailerons rigged 3° trailing edge up. The design CG is at 12 % of the

mean chord, 6.5 % static margin ahead of the neutral point (x 252 mm

from the nose datum): stable without a tail download penalty at speed.

Pitch and yaw come from two all-moving tail panels at 35° anhedral,

mixed like a V-tail, with a fixed fin on top. The Dutch roll is lightly

damped at low speed, so the flight controller's yaw damper is part of the

setup.

Flutter of the wing, ailerons and tail panels was analysed (strip theory

with the CAD-derived stiffness and masses): the lowest predicted

instability is 88 m/s, above 1.2 × the 60 m/s top stage. The test plan opens

the speed envelope in stages and measures the stiffness the margin

depends on.

SKY G | SKYG SPEED 60 | USER MANUAL | 6

# AERODYNAMICCHARACTERISTICS


Whole aircraft, VSPAERO vortex lattice with the fuselage panels; best L/D 10.2 at 6.0°; Cm about the design CG.

SKY G | SKYG SPEED 60 | USER MANUAL | 7

# PERFORMANCEANDSPEEDSTAGES

Motor | T-Motor F50 2207 2150KV
Propeller | Gemfan Vortex 5x7.5R (pusher) preferred
Battery | Tattu R-Line 4S 650 75C
Static thrust | 634 g at 27 A (thrust / weight 1.76)
Throttle cap (prop rpm rating) | 83 %
Top speed | 62 m/s as printed, 65 m/s finished
Full-throttle time | about 1.5 min per pack (bursts of ≤ 10 s)
Stage Vne | STAGE throttle limit | Expected level speed
30 m/s | 32 % | 23 m/s
35 m/s | 37 % | 28 m/s
40 m/s | 43 % | 32 m/s
45 m/s | 48 % | 36 m/s
50 m/s | 53 % | 40 m/s
55 m/s | 58 % | 44 m/s
60 m/s | 64 % | 48 m/s

No airspeed sensor: each stage is held by a throttle limit on a transmitter switch (LAUNCH =

full cap for the throw and climb-out only, STAGE = the limit). Level runs only; speed from

GPS two-way passes.

SKY G | SKYG SPEED 60 | USER MANUAL | 8

# FILES


Every printed part is supplied as STL (for printing) and

STEP (for editing), plus the complete assembly as one

STEP file. Left and right wing halves, ailerons and tail

panels are separate files because they are mirror

images. The interactive viewer in the package shows

every part, purchased item and cable in place.

SKY G | SKYG SPEED 60 | USER MANUAL | 9

# COMPARTMENTLAYOUT

BATTERY BAY; WING BAY; TAIL MODULE; NOSE BAY; nose; SKY G; SKYG SPEED 60; USER MANUAL

4S 650 pack, 60 × 31 × 21 mm max; slides x 100–130 for

balance; rear stop at x 160

Flight controller stack with the ESC on top, receiver,

aileron servo; reached with the wing off

Two tail servos, pushrods, horns and the motor; plugs off at

the MR30 and servo plugs

Camera and VTX (or the DJI O4 unit) in the removable
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

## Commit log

2026-09-30 Ailerons with fixed wingtip (C4-7d, C5-1d)
2026-10-01 Add order list (BOM)
2026-10-01 Side vents, DJI duct, thermal model
2026-10-01 Antenna placement
2026-10-01 C5-5 components, section cut overlay
2026-10-01 C5-6 aileron pin hinge and drive
2026-10-01 No airspeed sensor: stage throttle limits
2026-10-01 C5-7 tail pushrods, wiring, battery stop, ballast
2026-10-01 BOM corrections
2026-10-02 C5-9 ES9052MD servos
2026-10-02 SkyG Speed 120 (C7-2); collapsible side panel, explode slider on the stage
2026-10-02 Viewer: view, section-cut and explode controls in one toolbar row
2026-10-03 C8: printability pass 5 (support-free noses, separate VTX shelf and dome ring), wing 1 mm aft
2026-10-04 C8: all printed parts pass the print audit
2026-10-04 C7 and C8: all printed parts pass the print audit
2026-10-04 C5-C8: all printed parts pass the print audit
2026-10-04 Downloads (manual, BOM xlsx, wiring, ArduPilot) and fuselage diameter on every page
    [SkyG-Speed-120-BOM.xlsx, SkyG-Speed-180-BOM.xlsx, SkyG-Speed-60-BOM.xlsx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]
2026-10-04 Print files (3MF) and CAD (STEP) downloads; STEP link per part
    [AL-aileron-left.step, AR-aileron-right.step, F1-fuselage-front.step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]
2026-10-04 DJI dome nose on C8, smooth outlets, real cables on all four, print/CAD downloads
    [AL-aileron-left.step, AR-aileron-right.step, F1-fuselage-front.step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]
2026-10-04 Update C4 viewer (C5-9)
    [AL-aileron-left.step, AR-aileron-right.step, F1-fuselage-front.step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]
2026-10-07 SkyG Speed 90: printable F2 (wall-grown bridges, G-code audited), rear wing screw at LE + 58, 30 % lightning infill
    [AHL-aileron-horn-left.step, AHR-aileron-horn-right.step, AL-aileron-left.step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]
2026-10-07 SkyG Speed 90 revision C6-9: version numbers on every download, document and part file
    [AHL-aileron-horn-left.step, AHL-aileron-horn-left_C6-9.step, AHR-aileron-horn-right.step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]
2026-10-07 SkyG Speed 90 C6-9: directional stability corrected (Cn_beta +0.024)
    [SkyG-Speed-90-C6-9-BOM.xlsx]
2026-10-07 SkyG Speed 90 C6-9: ready-to-print sliced files with supports (H2S, H2D)
    [AHL-aileron-horn-left_C6-9.step, AHR-aileron-horn-right_C6-9.step, AL-aileron-left_C6-9.step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]
2026-10-07 SkyG Speed 90B (C6B-1): carbon-tube fuselage page with downloads; links from the other pages
    [AHL-aileron-horn-left_C6B-1.step, AHR-aileron-horn-right_C6B-1.step, AL-aileron-left_C6B-1.step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]
2026-10-07 SkyG Speed 90B: page moved to c6b/ (lower case)
    [AHL-aileron-horn-left_C6B-1.step, AHR-aileron-horn-right_C6B-1.step, AL-aileron-left_C6B-1.step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]
2026-10-07 SkyG Speed 90B C6B-2: no openings in the tube or hatch cover, steel wing screws, ASA fin, PETG-CF tail panels
    [AHL-aileron-horn-left_C6B-1.step, AHL-aileron-horn-left_C6B-2.step, AHR-aileron-horn-right_C6B-1.step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]
2026-10-08 SkyG Speed 90B C6B-3: flush screws on the tube (printed countersunk washers), PETG-CF horns, steel wing screws named everywhere
    [AHL-aileron-horn-left_C6B-2.step, AHL-aileron-horn-left_C6B-3.step, AHR-aileron-horn-right_C6B-2.step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]
2026-10-08 SkyG Speed 90B C6B-4: 98 mm hatch on flush screws (no magnets), USB-C socket for the FC, consistency gate
    [AHL-aileron-horn-left_C6B-3.step, AHL-aileron-horn-left_C6B-4.step, AHR-aileron-horn-right_C6B-3.step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]
2026-10-08 SkyG Speed 90B C6B-5: rectangular wing window + filler, hole edge distances, tail inlets underneath, four-screw tail joint
    [AHL-aileron-horn-left_C6B-4.step, AHL-aileron-horn-left_C6B-5.step, AHR-aileron-horn-right_C6B-4.step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]
2026-10-08 SkyG Speed 90B C6B-6: motor plate on screws, washers on every external screw, manuals without overlaps
    [AHL-aileron-horn-left_C6B-5.step, AHL-aileron-horn-left_C6B-6.step, AHR-aileron-horn-right_C6B-5.step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]
2026-10-08 SkyG Speed 90B C6B-7: 20 mm tube ring behind the wing, tail 7 mm aft, coupler screws back
    [AHL-aileron-horn-left_C6B-6.step, AHL-aileron-horn-left_C6B-7.step, AHR-aileron-horn-right_C6B-6.step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]
2026-10-08 SkyG Speed 90B C6B-7: 320 mm tube, four wing screws in steel cup washers, GPS cradle
    [AHL-aileron-horn-left_C6B-7.step, AHR-aileron-horn-right_C6B-7.step, AL-aileron-left_C6B-7.step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]
2026-10-08 SkyG Speed 90B C6B-7: design and media review gates, corrected manual pictures
    [SkyG-Speed-90B-C6B-7-BOM.xlsx]
2026-10-09 SkyG Speed 120B C7B-1: 50 mm carbon tube, 6S, packs charged in place
    [AHL-aileron-horn-left_C7B-1.step, AHR-aileron-horn-right_C7B-1.step, AL-aileron-left_C7B-1.step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]
2026-10-10 SkyG Speed 90B C6B-8: DJI nose duct insert, side NACA inlets, drain, motor plate fits, assembly and skin gates
    [AHL-aileron-horn-left_C6B-7.step, AHL-aileron-horn-left_C6B-8.step, AHR-aileron-horn-right_C6B-7.step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]
2026-10-13 SkyG Speed 90B C6B-16: hinge at 66 % chord, stiff tray, USB lead slot, DJI nose print fixes
